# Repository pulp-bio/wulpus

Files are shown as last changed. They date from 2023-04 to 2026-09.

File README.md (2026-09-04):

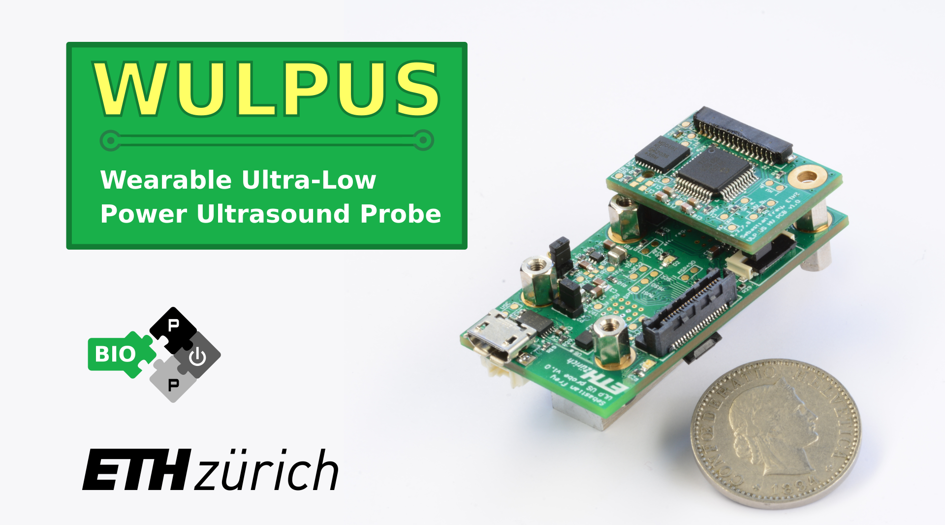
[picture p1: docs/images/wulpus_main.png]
WULPUS main


# WULPUS v1.2.4
## Wearable Ultra Low-Power Ultrasound

# Introduction

This repository contains the work in progress on the WULPUS ultrasound probe.

WULPUS is a truly wearable ultra-low-power open research ultrasound platform. 

The probe has the following features:
- **8 channels** (time-multiplexed)
- **8 Msps** Analog-to-Digital converter (12 bit resolution)
- **30.8 dB** Programable-Gain Amplifier + **10 dB** Operational Amplifier
- **Bluetooth Low Energy** (BLE) wireless link (320 kbps throughput)
- Up to **50 acquisitions per-second** (APS) (400 samples per acquisition, raw data streaming mode)
- **Compactness and light weight** (46 x 25 mm footprint, 9 g)
- **Ultra-Low Power** consumption of **22 mW** (raw data streaming mode, 50 APS)

# WULPUS system diagram

WULPUS probe comprises two printed circuit boards (PCBs):
- Acquisition PCB: featuring an ultrasound MCU (MSP430FR5043) and BLE MCU (nRF52832)
- High-Voltage PCB: featuring a High-voltage multiplexer (HV MUX), a transmit/receive switch, and a MOSFET driver.

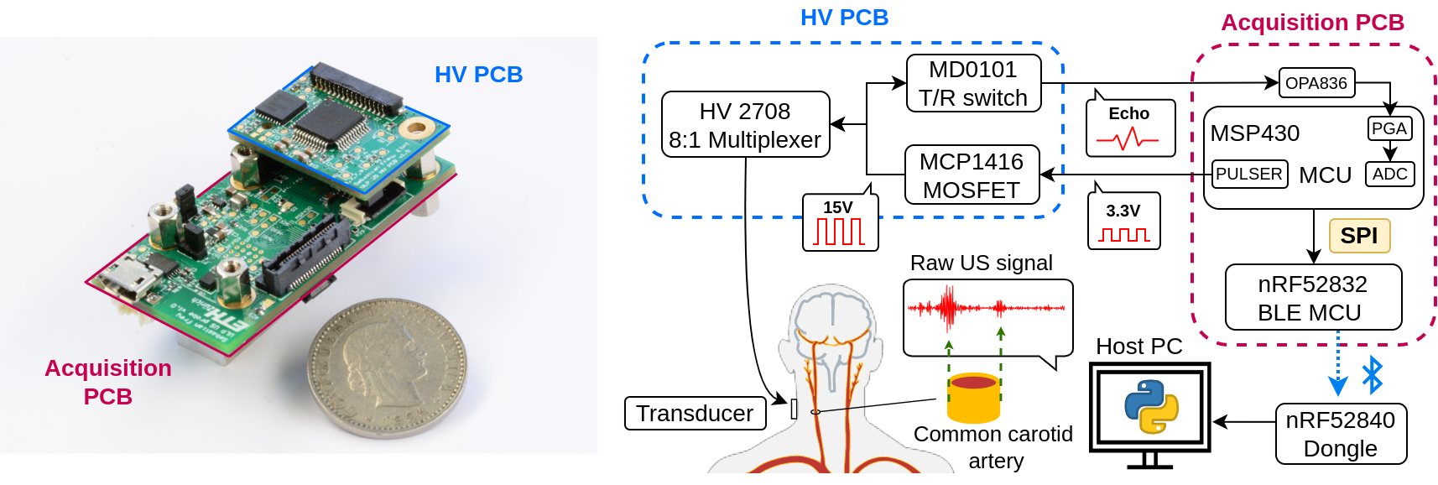
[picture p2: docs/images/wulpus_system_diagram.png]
WULPUS System Diagram

WULPUS System Diagram

# Structure of the repository

This repository has the following folders:

- `fw`, containing the firmware source code, namely:
    - source code for the nRF52832 MCU of the WULPUS probe, located at `fw/nrf52/ble_peripheral/US_probe_nRF52_firmware`
    - source code for the nRF52840 USB dongle, located at `fw/nrf52/peripheral/US_probe_dongle_firmware`
    - source code for the MSP430 ultrasound MCU, located at `fw/msp430`
- `sw`, containing the Python code for the WULPUS Graphical User Interface (web-based version).
 
- `hw`, containing the CAD source files for 
    - WULPUS Acquisition PCB (located at `hw/wulpus_acquisition_pcb`)
    - WULPUS High-Voltage PCB (located at `hw/wulpus_hv_pcb`)
    - WULPUS Programmer PCBs (located at `hw/wulpus_programmer_pcbs`)
    - WULPUS Silicone Rubber package (located at `hw/wulpus_silicone_package`)

- `docs`, containing the project documentation (e.g., images of the device, user manual, ...)

# Documentation 

The comprehensive [WULPUS User Manual](docs/wulpus_user_manual.pdf) can be found in the `docs/` folder. It covers everything about WULPUS, from assembly instructions to example measurements and troubleshooting, making the platform user-friendly for everyone, regardless of technical expertise.

# How to use?

Please find the detailed instructions in chapter 2 of the [WULPUS User Manual](docs/wulpus_user_manual.pdf).

In a nutshell, to build your own instance of WULPUS, the following steps should be completed:
1. *PCBs manufacturing and assembly*<br>
   You can find the design files (Altium source files, schematics, bills of materials) under the `hw` folder.
2. *Flashing MSP430 firmware*<br>
   You can find the instructions on setting up the toolchain, compiling the firmware and flashing the MSP430 MCU in the `fw/msp430` folder.
3. *Flashing nRF52 MCU and USB dongle firmware*<br>
   You can find the instructions on setting-up the toolchain, compiling the firmware, flashing the nRF52 MCU and USB dongle in the `fw/nrf52` folder.
4. *GUI installation on the host PC*<br>
   Choose one of the following interfaces depending on your application:
   - **BioGUI** *(Recommended for general use & HMI applications)*: Modular PySide6 GUI for acquiring and visualizing bio-signals from different sources. Follow the setup instructions in the [BioGUI repository](https://github.com/pulp-bio/biogui).
   - **Web-based GUI** *(Recommended for NDT applications & acquisition sequences)*: Features a React/Vite frontend and FastAPI backend. Follow the setup instructions in [`sw/`](sw/).
   - **Legacy Jupyter Notebook GUI** *(Deprecated / not recommended for new projects)*: Legacy interactive notebooks are located in [`sw/jupyter notebook (legacy)/`](<sw/jupyter notebook (legacy)/>).

# Usage

Please refer to chapter 3 of the [WULPUS User Manual](docs/wulpus_user_manual.pdf) for detailed information.

Starting a measurement with WULPUS can be accomplished in three simple steps:
- Power up the probe, either from the micro-USB connector or from the battery connector
- Connect the USB dongle to the host PC
- Launch your chosen interface (**[BioGUI repository](https://github.com/pulp-bio/biogui)** or the **Web-based GUI** in [`sw/`](sw/)).

# Citation
If you would like to reference the project, please cite the following paper:

```
@inproceedings{frey2022wulpus,
  title={WULPUS: a Wearable Ultra Low-Power Ultrasound probe for multi-day monitoring of carotid artery and muscle activity},
  author={Frey, Sebastian and Vostrikov, Sergei and Benini, Luca and Cossettini, Andrea},
  booktitle={2022 IEEE International Ultrasonics Symposium (IUS)},
  pages={1--4},
  year={2022},
  organization={IEEE}
}
```
# Works that use WULPUS

[1] Vostrikov, Sergei, et al. "Hand gesture recognition via wearable ultra-low power ultrasound and gradient-boosted tree classifiers." 2023 IEEE International Ultrasonics Symposium (IUS). IEEE, 2023.

[2] Vostrikov, Sergei, Luca Benini, and Andrea Cossettini. "Complete Cardiorespiratory Monitoring via Wearable Ultra Low Power Ultrasound." 2023 IEEE International Ultrasonics Symposium (IUS). IEEE, 2023.

[3] Frey, Sebastian, et al. "A wearable ultra-low-power semg-triggered ultrasound system for long-term muscle activity monitoring." 2023 IEEE International Ultrasonics Symposium (IUS). IEEE, 2023.

[4] Vostrikov S, Anderegg M, Benini L, Cossettini A. "Unsupervised Feature Extraction from Raw Data for Gesture Recognition with Wearable Ultra Low-Power Ultrasound." IEEE Transactions on Ultrasonics, Ferroelectrics, and Frequency Control. 2024 May 24.

[5] Spacone G, Vostrikov S, Kartsch V, Benatti S, Benini L, Cossettini A. "Tracking of Wrist and Hand Kinematics with Ultra Low Power Wearable A-mode Ultrasound." IEEE Transactions on Biomedical Circuits and Systems. 2024 Sep 23.

[6] Spacone, Giusy, et al. "Wearable and Ultra-Low-Power Fusion of EMG and A-Mode US for Hand-Wrist Kinematic Tracking." 2025 IEEE Biomedical Circuits and Systems Conference (BioCAS). IEEE, 2025.

[7] Spacone, Giusy, et al. "Towards Fully Wearable Muscle Fatigue Assessment with A-mode Ultrasound." 2025 IEEE International Ultrasonics Symposium (IUS). IEEE, 2025.

[8] Spacone, Giusy, et al. "Towards Whole Hand and Wrist Kinematic Tracking with a Wearable A-Mode Ultrasound Probe." IEEE Open Journal of Ultrasonics, Ferroelectrics, and Frequency Control. 2026.

# Authors

The WULPUS system was developed at the [Integrated Systems Laboratory (IIS)](https://iis.ee.ethz.ch/) at ETH Zurich by:
- [Sergei Vostrikov](https://scholar.google.com/citations?user=a0KNUooAAAAJ&hl=en) (Firmware, Software, Open-Sourcing, Documentation)
- [Sebastian Frey](https://scholar.google.com/citations?user=7jhiqz4AAAAJ&hl=en) (Firmware, PCB design, Documentation)
- [Luca Benini](https://scholar.google.com/citations?hl=en&user=8riq3sYAAAAJ) (Supervision, Conceptualization)
- [Andrea Cossettini](https://scholar.google.com/citations?user=d8O91jIAAAAJ&hl=en) (Supervision, Project administration)

Thanks to all the people who contributed to the WULPUS platform:
- [Cédric Hirschi](https://www.linkedin.com/in/c%C3%A9dric-cyril-hirschi-09624021b/) (GUI improvements, Documentation)
- [Josquin Tille](https://www.linkedin.com/in/josquin-tille-829a341a7/) (Silicone package design, Documentation)
- [William Bruderer](https://www.linkedin.com/in/william-bruderer-59ba9b26b/) (Documentation)
- [Louis Dod](https://github.com/13Bytes) (GUI Rework)

# License
The following files are released under Apache License 2.0 (`Apache-2.0`) (see `sw/LICENSE`):

- `sw/`

The following files are released under Solderpad v0.51 (`SHL-0.51`) (see `hw/LICENSE`):

- `hw/`

The following files are released under Creative Commons Attribution 4.0 International
License (`CC-BY-4.0`) (see `docs/images/LICENSE`):

- `docs/images/`

The `fw/msp430/` and `fw/nrf52/` directories contain third-party sources that come with their own
licenses. See the respective folders and source files for the licenses used.

## Limitation of Liability
In no event and under no legal theory, whether in tort (including negligence), contract, or otherwise, unless required by applicable law (such as deliberate and grossly negligent acts) or agreed to in writing, shall any Contributor be liable to You for damages, including any direct, indirect, special, incidental, or consequential damages of any character arising as a result of this License or out of the use or inability to use the Work (including but not limited to damages for loss of goodwill, work stoppage, computer failure or malfunction, or any and all other commercial damages or losses), even if such Contributor has been advised of the possibility of such damages.

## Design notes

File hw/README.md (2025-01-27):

# WULPUS HW design files
This directory contains the design files for the printed circuit boards (PCBs) of the WULPUS project and 3D models required to fabricate soft silicone rubber package for WULPUS.
The following directories corresponds to PCB projects:

-`hw/wulpus_acquisition_pcb`
-`hw/wulpus_hv_pcb`
-`hw/wulpus_programmer_pcbs`
-`hw/wulpus_silicone_package`

 Inside you can find the Altium CAD design files and generated schematics (.pdf), bill of materials (.xlsx) and Gerber files located in the `docs` subfolders.

 The following repository contains the 3D models required to fabricate soft silicone rubber package for WULPUS:
 -`hw/wulpus_silicone_package`

# License
The source design files are licensed under Solderpad v0.51 (`SHL-0.51`) license. Please, check the `hw/LICENSE` file for details.

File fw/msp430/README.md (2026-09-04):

# WULPUS source files for MSP430 Ultrasound MCU firmware project
This directory contains the source firmware files for 
- MSP430FR5043 Ultrasound MCU (`fw/msp430/wulpus_msp430_firmware`) mounted on the WULPUS acquisition PCB 

# How to get started?

1. Follow the file `fw/msp430/how_to_setup_msp_430_toolchain_and_flash.md` to install the toolchain and SDK
2. Follow the same file to flash the MSP430 MCU on the WULPUS acquisition PCB.

# License
The files in the `fw/msp430/wulpus_msp430_firmware` directory contain third-party sources that come with their own licenses (primarily BSD and Apache 2.0 License). See the respective folders and source files' headers for the licenses used.

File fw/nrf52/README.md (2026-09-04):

# WULPUS source files for nRF BLE MCU firmware projects
This directory contains the source files for 
- nRF52832 BLE MCU (`fw/nrf52/ble_peripheral`) mounted on the WULPUS acquisition PCB
- nRF52840 Dongle (`fw/nrf52/peripheral`) used to receive the ultrasound data on a host PC

# How to get started?

1. Follow the file `fw/nrf52/how_to_setup_nRF52_toolchain.md` to install the toolchain and SDK
2. Follow the file `fw/nrf52/how_to_flash_nrf52832.md` to flash the nRF MCU on the WULPUS acquisition PCB
3. Follow the file `fw/nrf52/how_to_flash_nrf52840_dongle.md` to flash the nRF52840 Dongle

# License
The files in the `fw/nrf52/ble_peripheral` and `fw/nrf52/peripheral` directories contain third-party sources that come with their own licenses. See the respective folders and source files' headers for the licenses used.

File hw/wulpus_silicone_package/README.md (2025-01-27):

# WULPUS Silicone Rubber Package Design Files
This directory contains the design files for the molds required to fabricate the soft silicone rubber package for WULPUS.

## Design Files for FDM 3D Printers
For the main package, use the following design files optimized for FDM 3D printing:
- `wulpus_inside_mold_fdm.stl`
- `wulpus_outside_mold_fdm.stl`

## Design Files for SLA 3D Printers
If you plan to order molds from an external supplier using SLA technology, please use these files:
- `wulpus_inside_mold_resin.stl`
- `wulpus_outside_mold_resin.stl`

## Compatibility Note
The above sets of 3D models are tailored to the specific tolerances required for FDM and SLA technologies. 

## Silicone Cap Mold
The following 3D model can be used with both FDM and SLA printers:
- `wulpus_silicone_cap_mold.stl`

## Fabrication Instructions
For detailed instructions on the fabrication process, refer to the [WULPUS User Manual](../../docs/wulpus_user_manual.pdf).

# License
The source design files are licensed under the Solderpad v0.51 (`SHL-0.51`) license. For more details, please refer to the `hw/LICENSE` file.

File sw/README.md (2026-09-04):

# WULPUS GUI source files
This directory contains the source files for WULPUS Graphical User Interface and an example Jupyter notebook ([wulpus_gui.ipynb](./jupyter%20notebook%20%28legacy%29/wulpus_gui.ipynb)).

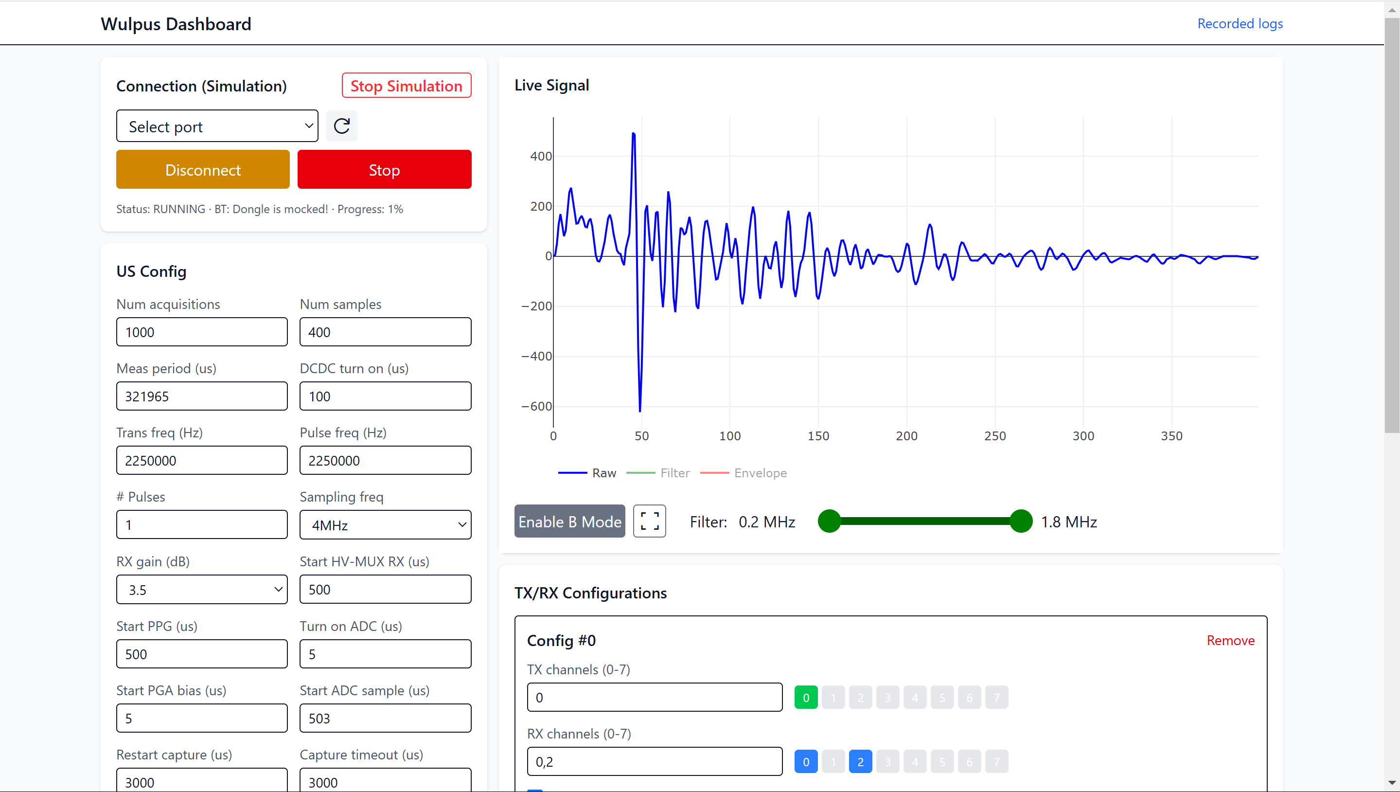
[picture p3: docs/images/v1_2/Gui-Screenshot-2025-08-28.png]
WULPUS GUI Screenshot


# How to get started?
## Prebuilt GUI (Windows)
The simplest way to run the WULPUS GUI on Windows is to use the prebuilt executable:

1. Download the latest `wulpus-all-in-one` artifact from the [WULPUS releases page](https://github.com/pulp-bio/wulpus/releases/latest).
2. Extract the downloaded zip file.
3. Start `main.exe`.
4. Open [http://127.0.0.1:8000/](http://127.0.0.1:8000/) in your browser.

Windows may show a security warning because the executable is not signed. If you downloaded it from the official release page, choose "More info" and then "Run anyway".

## Run from source
The Jupyter notebook requires only the Python dependencies, while the web-based GUI also requires the Node.js dependencies.

### Install dependencies
Install [uv](https://docs.astral.sh/uv/getting-started/installation/), then install the Python dependencies from `sw`:

```sh
uv sync
```

Install the Node.js dependencies from `sw/wulpus-frontend`:

```sh
npm i
```

### Initial build
Build the frontend and copy the results into the backend's production frontend directory:

```sh
python build.py
```

### User interface
How to launch the user interface from source:

- After completing the initial build, open a new terminal and navigate into `/sw`
- Start the backend with uv:
```
    uv run python -m wulpus.main
```
You should be able to open a browser of your choice and visit [http://127.0.0.1:8000/](http://127.0.0.1:8000/)

#### Using the log file
The log recorded by the user interface is a zip file called `wulpus-{date}-id-{connection}.zip`.
The date is the start of the recording, with the connection describes which wulpus was used (MAC address or COM port).
It contains the config from the job, as well as the data in a [parquet](https://parquet.apache.org/) file.

The parquet file contains the following rows:
- `tx`: list of channels used for sending
- `rx`: list of channels used for receiving
- `aq_number`: ID increased by the wulpus (can be used to detect lost frames)
- `log_version`: the current version of the log-format. Constant over the whole file. 
- `tx_rx_id`: the index of the tx-rx-config used
- `0`, `1`, `2`, ...`{num samples - 1}`: the actual data, readout from ADC
- `__index_level_0__`: unix timestamp in us

You can use the jupyter notebook [visualize_log.ipynb](visualize_log.ipynb) to load a single or a set of multiple measurements and evaluate them.
There is also [MATLAB_load_wulpus_log.m](MATLAB_load_wulpus_log.m) to help import the logs into MATLAB.

### Jupyter notebook (legacy)
How to Launch an example Jupyter notebook:
- In a terminal launch:
```
    uv run --extra notebook jupyter notebook
```
This opens a webpage: Navigate to `jupyter notebook (legacy)` and click on `wulpus_gui.ipynb`.
Then, follow the instructions in the Notebook.

# More details
The folder structure inside `/sw` is as follows:
- `wulpus-frontend` is a React project for the interface you see in your browser
- `wulpus` is a FastAPI server that controls communication with wulpus.
- `jupyter notebook (legacy)` is a standalone python-only solution which uses a jupyter notebook for controlling wulpus. 

During the build-step of `wulpus-frontend`, the build results are copied inside `wulpus\production-frontend`. This is how the frontend can be served from the `wulpus` FastAPI project.

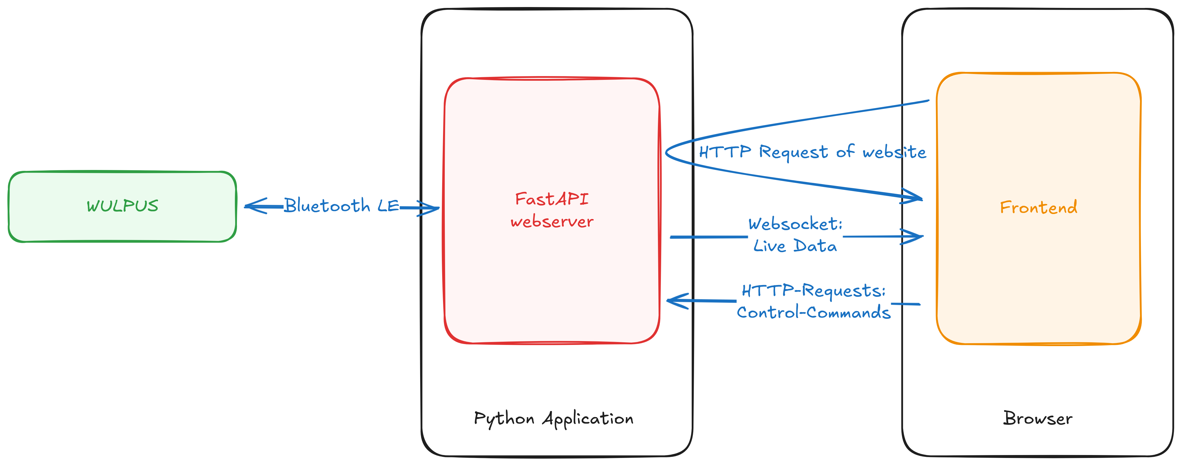
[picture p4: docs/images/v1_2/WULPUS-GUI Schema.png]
WULPUS GUI Schema


## Development
If you want to work on the frontend, it's easier to run the backend (`wulpus`) and the frontend (`wulpus-frontend`) separately.
This way you don't have to build after each step.

You can start the backend as usual (see above `uv run python -m wulpus.main`), but instead of visiting [http://127.0.0.1:8000/](http://127.0.0.1:8000/) in your browser, you start the development environment of the frontend:
- Open an additional terminal at `\sw\wulpus-frontend`
- run 
```
    npm run dev
```
- open the displayed link in your browser (probably [http://localhost:5173/](http://localhost:5173/))

This way, you access the frontend through its own dev server, which does hot reloading.
It still accesses the same backend, so everything still works exactly the same.

# License
The source files are released under Apache v2.0 (`Apache-2.0`) license unless noted otherwise, please refer to the `sw/LICENSE` file for details.

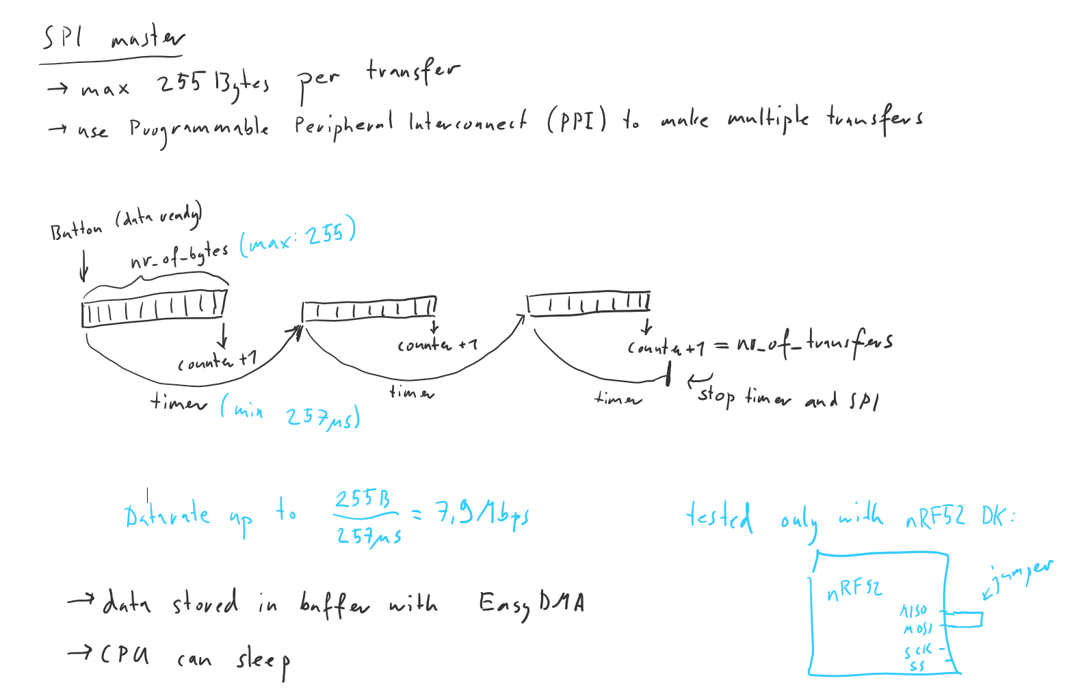
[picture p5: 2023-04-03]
fw/nrf52/ble_peripheral/US_probe_nRF52_firmware/Explanation_of_SPI_transaction.PNG

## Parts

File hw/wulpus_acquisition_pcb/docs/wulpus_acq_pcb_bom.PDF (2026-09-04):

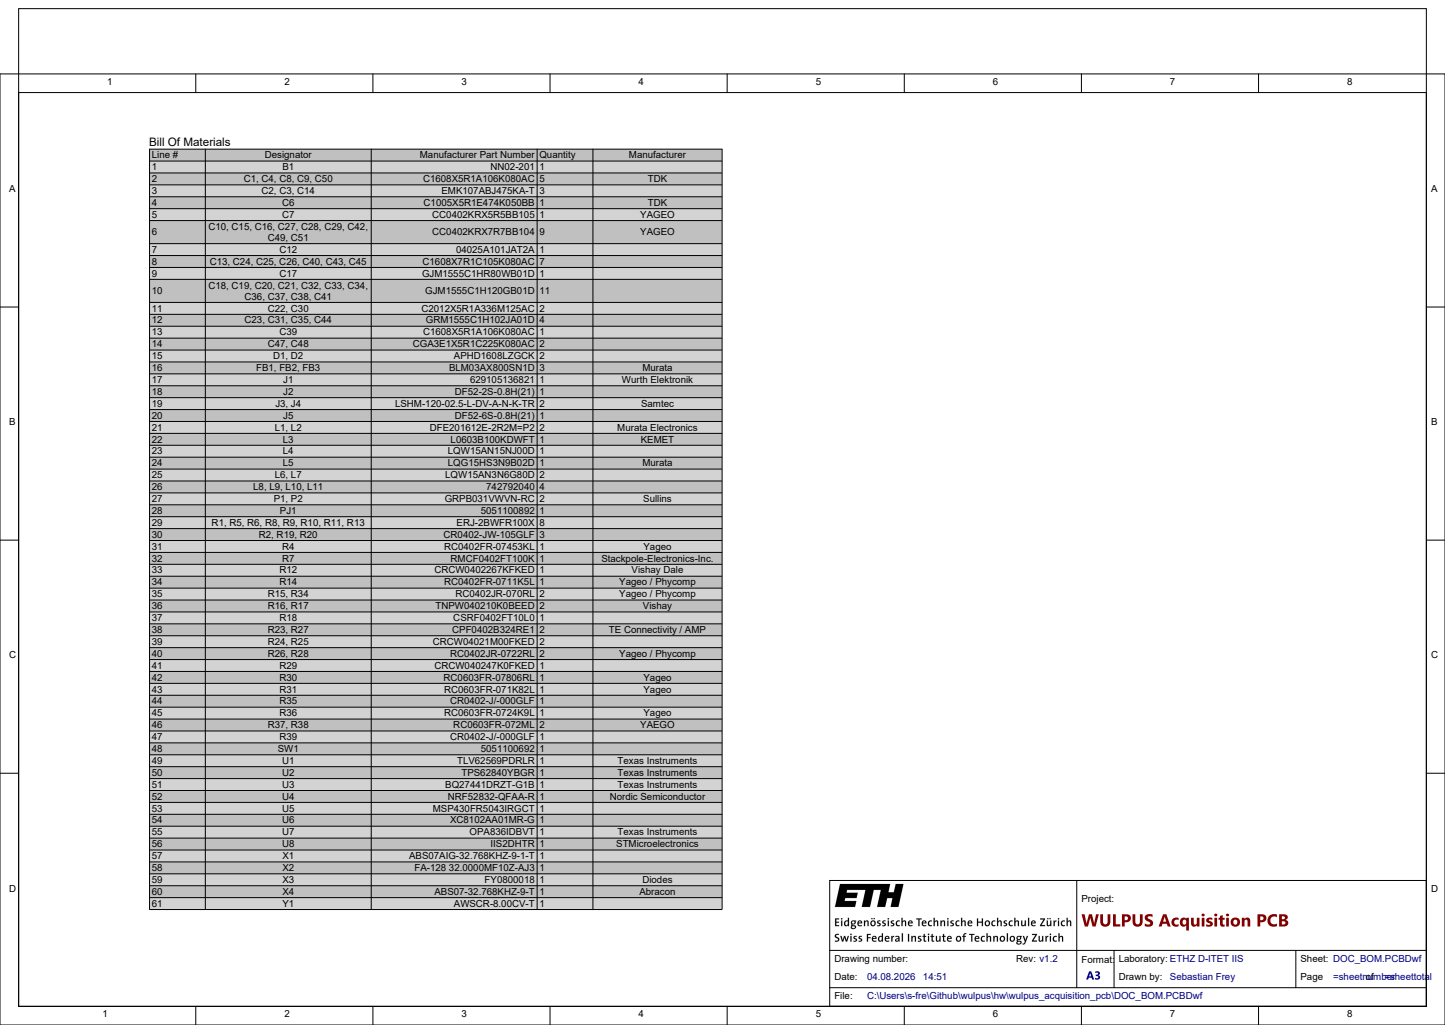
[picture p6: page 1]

Line # | Designator | Manufacturer Part Number | Quantity | Manufacturer
1 | B1 | NN02-201 | 1
2 | C1, C4, C8, C9, C50 | C1608X5R1A106K080AC | 5 | TDK
3 | C2, C3, C14 | EMK107ABJ475KA-T | 3
4 | C6 | C1005X5R1E474K050BB | 1 | TDK
5 | C7 | CC0402KRX5R5BB105 | 1 | YAGEO
6 | C10, C15, C16, C27, C28, C29, C42, C49, C51 | CC0402KRX7R7BB104 | 9 | YAGEO

7 | C12 | 04025A101JAT2A | 1
8 | C13, C24, C25, C26, C40, C43, C45 | C1608X7R1C105K080AC | 7
9 | C17 | GJM1555C1HR80WB01D | 1
10 | C18, C19, C20, C21, C32, C33, C34, C36, C37, C38, C41 | GJM1555C1H120GB01D | 11

11 | C22, C30 | C2012X5R1A336M125AC | 2
12 | C23, C31, C35, C44 | GRM1555C1H102JA01D | 4
13 | C39 | C1608X5R1A106K080AC | 1
14 | C47, C48 | CGA3E1X5R1C225K080AC | 2
15 | D1, D2 | APHD1608LZGCK | 2
16 | FB1, FB2, FB3 | BLM03AX800SN1D | 3 | Murata
17 | J1 | 629105136821 | 1 | Wurth Elektronik
18 | J2 | DF52-2S-0.8H(21) | 1
19 | J3, J4 | LSHM-120-02.5-L-DV-A-N-K-TR | 2 | Samtec
20 | J5 | DF52-6S-0.8H(21) | 1
21 | L1, L2 | DFE201612E-2R2M=P2 | 2 | Murata Electronics
22 | L3 | L0603B100KDWFT | 1 | KEMET
23 | L4 | LQW15AN15NJ00D | 1
24 | L5 | LQG15HS3N9B02D | 1 | Murata
25 | L6, L7 | LQW15AN3N6G80D | 2
26 | L8, L9, L10, L11 | 742792040 | 4
27 | P1, P2 | GRPB031VWVN-RC | 2 | Sullins
28 | PJ1 | 5051100892 | 1
29 | R1, R5, R6, R8, R9, R10, R11, R13 | ERJ-2BWFR100X | 8
30 | R2, R19, R20 | CR0402-JW-105GLF | 3

32 | R7 | RMCF0402FT100K | 1 | Stackpole-Electronics-Inc.
33 | R12 | CRCW0402267KFKED | 1 | Vishay Dale
34 | R14 | RC0402FR-0711K5L | 1 | Yageo / Phycomp
35 | R15, R34 | RC0402JR-070RL | 2 | Yageo / Phycomp
36 | R16, R17 | TNPW040210K0BEED | 2 | Vishay
37 | R18 | CSRF0402FT10L0 | 1
38 | R23, R27 | CPF0402B324RE1 | 2 | TE Connectivity / AMP
39 | R24, R25 | CRCW04021M00FKED | 2
40 | R26, R28 | RC0402JR-0722RL | 2 | Yageo / Phycomp
41 | R29 | CRCW040247K0FKED | 1
42 | R30 | RC0603FR-07806RL | 1 | Yageo
43 | R31 | RC0603FR-071K82L | 1 | Yageo
44 | R35 | CR0402-J/-000GLF | 1
45 | R36 | RC0603FR-0724K9L | 1 | Yageo
46 | R37, R38 | RC0603FR-072ML | 2 | YAEGO
47 | R39 | CR0402-J/-000GLF | 1
48 | SW1 | 5051100692 | 1
49 | U1 | TLV62569PDRLR | 1 | Texas Instruments
50 | U2 | TPS62840YBGR | 1 | Texas Instruments
51 | U3 | BQ27441DRZT-G1B | 1 | Texas Instruments
52 | U4 | NRF52832-QFAA-R | 1 | Nordic Semiconductor
53 | U5 | MSP430FR5043IRGCT | 1
54 | U6 | XC8102AA01MR-G | 1
55 | U7 | OPA836IDBVT | 1 | Texas Instruments
56 | U8 | IIS2DHTR | 1 | STMicroelectronics
57 | X1 | ABS07AIG-32.768KHZ-9-1-T | 1
58 | X2 | FA-128 32.0000MF10Z-AJ3 | 1
59 | X3 | FY0800018 | 1 | Diodes
60 | X4 | ABS07-32.768KHZ-9-T | 1 | Abracon
61 | Y1 | AWSCR-8.00CV-T | 1

Project:

Drawing number: Rev: v1.2 Date: 04.08.2026 14:51 | Format: | Laboratory: ETHZ D-ITET IIS Drawn by: Sebastian Frey | Sheet: DOC_BOM.PCBDwf Page =sheetnumber of =sheettotal

C:\Users\s-fre\Github\wulpus\hw\wulpus_acquisition_pcb\DOC_BOM.PCBDwf

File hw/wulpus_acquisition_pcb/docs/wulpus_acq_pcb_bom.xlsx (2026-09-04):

Designator | Comment | Quantity | Manufacturer
B1 | NN02-201 | 1
C1, C4, C8, C9, C39, C50 | C1608X5R1A106K080AC | 6 | TDK, [NoParam]
C2, C3, C14 | EMK107ABJ475KA-T | 3
C6 | C1005X5R1E474K050BB | 1 | TDK
C7 | CC0402KRX5R5BB105 | 1 | YAGEO
C10, C15, C16, C27, C28, C29, C42, C49, C51 | CC0402KRX7R7BB104 | 9 | YAGEO
C12 | 04025A101JAT2A | 1
C13, C24, C25, C26, C40, C43, C45 | C1608X7R1C105K080AC | 7
C17 | GJM1555C1HR80WB01D | 1
C18, C19, C20, C21, C32, C33, C34, C36, C37, C38, C41 | GJM1555C1H120GB01D | 11
C22, C30 | C2012X5R1A336M125AC | 2
C23, C31, C35, C44 | GRM1555C1H102JA01D | 4
C47, C48 | GRM188R61C225KE15D | 2
D1, D2 | APHD1608LZGCK | 2
FB1, FB2, FB3 | BLM03AX800SN1D | 3 | Murata
J1 | 629105136821 | 1 | Wurth Elektronik
J2 | DF52-2S-0.8H(21) | 1
J3, J4 | LSHM-120-02.5-L-DV-A-N-K-TR | 2 | Samtec
J5 | DF52-6S-0.8H(21) | 1
L1, L2 | DFE201612E-2R2M=P2 | 2 | Murata Electronics
L3 | L0603B100KDWFT | 1 | KEMET
L4 | LQW15AN15NJ00D | 1
L5 | LQG15HS3N9B02D | 1 | Murata
L6, L7 | LQW15AN3N6G80D | 2
L8, L9, L10, L11 | 742792040 | 4
P1, P2 | GRPB031VWVN-RC | 2 | Sullins
PJ1 | 5051100892 | 1
R1, R5, R6, R8, R9, R10, R11, R13 | ERJ-2BWFR100X | 8
R2, R19, R20 | CR0402-JW-105GLF | 3
R4 | RC0402FR-07453KL | 1 | Yageo
R7 | RMCF0402FT100K | 1 | Stackpole-Electronics-Inc.
R12 | CRCW0402267KFKED | 1 | Vishay Dale
R14 | RC0402FR-0711K5L | 1 | Yageo / Phycomp
R15, R34 | RC0402JR-070RL | 2 | Yageo / Phycomp
R16, R17 | TNPW040210K0BEED | 2 | Vishay
R18 | CSRF0402FT10L0 | 1
R23, R27 | CPF0402B324RE1 | 2 | TE Connectivity / AMP
R24, R25 | CRCW04021M00FKED | 2
R26, R28 | RC0402JR-0722RL | 2 | Yageo / Phycomp
R29 | CRCW040247K0FKED | 1
R30 | RC0603FR-07806RL | 1 | Yageo
R31 | RC0603FR-071K82L | 1 | Yageo
R35, R39 | CR0402-J/-000GLF | 2
R36 | RC0603FR-0724K9L | 1 | Yageo
R37, R38 | RC0603FR-072ML | 2 | YAEGO
SW1 | 5051100692 | 1
U1 | TLV62569PDRLR | 1 | Texas Instruments
U2 | TPS62840YBGR | 1 | Texas Instruments
U3 | BQ27441DRZT-G1B | 1 | Texas Instruments
U4 | NRF52832-QFAA-R | 1 | Nordic Semiconductor
U5 | MSP430FR5043IRGCT | 1
U6 | XC8102AA01MR-G | 1
U7 | OPA836IDBVT | 1 | Texas Instruments
U8 | IIS2DHTR | 1 | STMicroelectronics
X1 | ABS07AIG-32.768KHZ-9-1-T | 1
X2 | FA-128 32.0000MF10Z-AJ3 | 1
X3 | FY0800018 | 1 | Diodes
X4 | ABS07-32.768KHZ-9-T | 1 | Abracon
Y1 | AWSCR-8.00CV-T | 1

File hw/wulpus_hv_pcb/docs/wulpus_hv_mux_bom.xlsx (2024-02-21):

Designator | Manufacturer Part Number | Quantity | Manufacturer
C1 | 06036D475KAT2A | 1
C2 | C0402C479C5GACTU | 1 | Kemet
C3, C4 | GRM188R61H225KE11D | 2
C5 | C0603C104M5RACTU | 1 | KEMET
C6 | GMK316BJ105KLHT | 1
C7, C8 | GRM188R60J106ME47D | 2
C12, C14, C18, C21 | C1608X5R1H105K080AB | 4 | TDK
C13, C15, C19, C22 | CC0603KRX7R9BB104 | 4 | YAGEO
C17 | CL05B103KB5NNNC | 1
D1 | ZHCS400QTA | 1 | Diodes
FB1 | BLM18PG300SH1D | 1
J1 | LSHM-120-02.5-L-DV-A-N-K-TR | 1 | Samtec
J2 | DF52-16S-0.8H(21) | 1
L1 | B82422A1103K100 | 1 | EPCOS-(TDK)
L2 | NR3012T4R7M | 1
R1, R4, R6, R8 | CSR0402FK1R00 | 4
R2, R3, R19 | ERJ-2GEJ101X | 3 | Panasonic
R5 | RC0402FR-072ML | 1 | Yageo / Phycomp
R7 | ERJ-2RKF1783X | 1 | Panasonic
R10, R11, R12, R13, R14, R15, R16, R17, R18, R21 | RC0402JR-070RL | 10 | Yageo / Phycomp
U1 | LT1945IMS#PBF | 1 | Linear Technology
U2 | TPS61222DCKR | 1 | Texas Instruments
U3, U6 | MCP1416T-E/OT | 2
U4 | HV2707T-C/R8X | 1 | Microchip
U5 | MD0101K6-G | 1

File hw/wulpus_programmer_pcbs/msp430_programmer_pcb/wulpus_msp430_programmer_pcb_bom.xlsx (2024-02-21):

Designator | Manufacturer Part Number | Quantity | Manufacturer
CONN_JW1 | 5051100892 | 1 | Molex
J_OLMX1 | SAMTEC-TST-110-01-X-DJ | 1 | Samtec

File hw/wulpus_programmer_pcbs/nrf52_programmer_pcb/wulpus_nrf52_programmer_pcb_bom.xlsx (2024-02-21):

Designator | Manufacturer Part Number | Quantity | Manufacturer
CONN_SWDN1 | 5051100692 | 1 | Molex
S_NRDC1 | SAMTEC-TST-110-01-X-DJ | 1 | Samtec

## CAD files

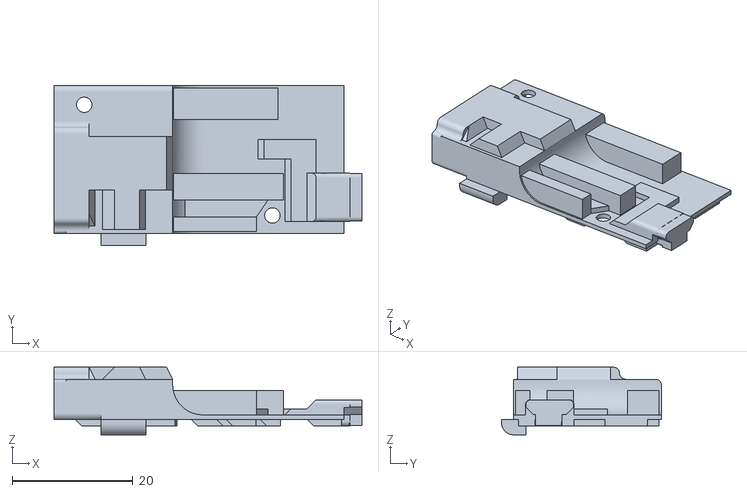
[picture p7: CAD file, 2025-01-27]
hw/wulpus_silicone_package/wulpus_inside_mold_resin.stl
51.0 x 26.5 x 11.2

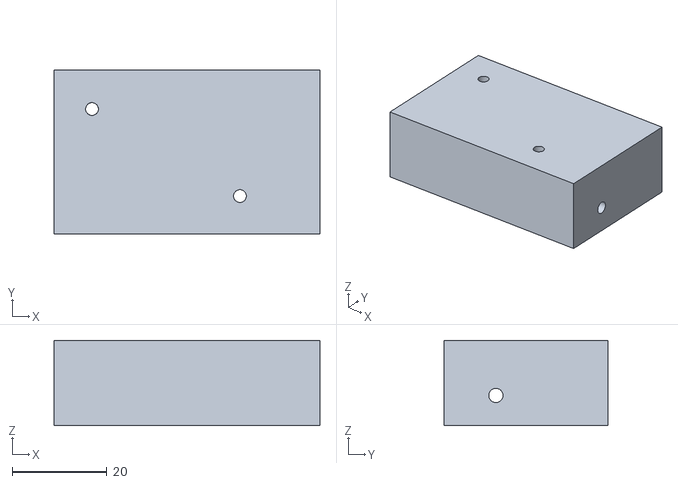
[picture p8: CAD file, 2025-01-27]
hw/wulpus_silicone_package/wulpus_outside_mold_fdm.stl
56.0 x 34.5 x 18.0

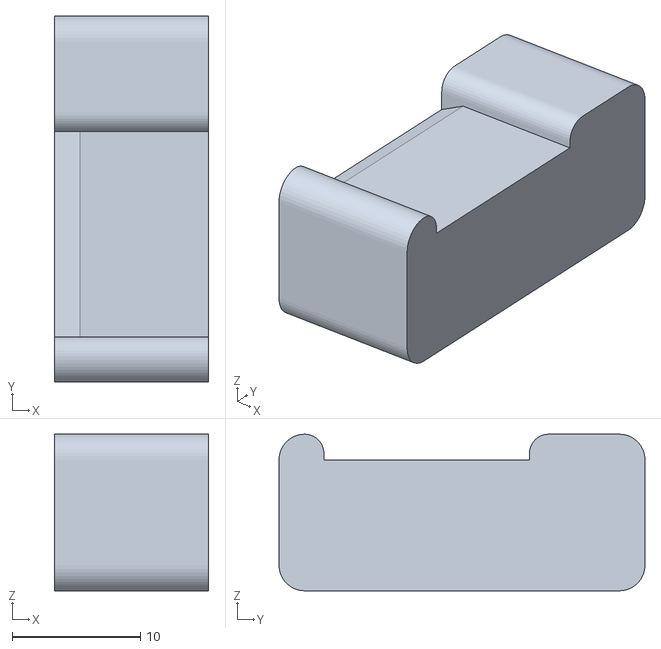
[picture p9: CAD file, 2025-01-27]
hw/wulpus_silicone_package/wulpus_silicone_cap_mold.stl
12.0 x 28.5 x 12.2

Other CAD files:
hw/wulpus_silicone_package/wulpus_outside_mold_resin.stl
hw/wulpus_silicone_package/wulpus_inside_mold_fdm.stl

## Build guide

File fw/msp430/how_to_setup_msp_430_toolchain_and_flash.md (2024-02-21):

# Setup of the TI MSP430 toolchain

### TI Code Composer Studio (CCS) (V11.0.0.00012):
`https://www.ti.com/tool/CCSTUDIO#downloads`
- Download the single file installer, extract it and run the ccs_setup_11.0.0.00012 file
- Choose custom installation
- In "Select Components", select MSP430 ultra-low power MCUs and finish the installation

# Flash the firmware to the MSP430

### To flash the MSP430 firmware:
Open the project in Code Composer Studio (CCS)
- Open CCS, set the workspace to default value
- Select File > Open Projects from File System...
- Select Directory, set it to `/fw/msp430/wulpus_msp430_firmware` and then click Finish
- Select Project > Build Configurations > Set Active > Debug
- Build the project
- Connect the MSP FET programmer to the US probe using the 8-pin Molex connector according to the diagram in the User Guide.
- Power the US probe with a battery or USB (Set the jumper P2 accordingly)
- Flash the code: Click on the Flash icon (if necessary select a binary file called `wulpus_msp430_firmware.out`)

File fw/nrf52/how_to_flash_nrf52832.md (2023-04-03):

# Flash the Nordic nRF52832 with Segger Embedded Studio (SES)

First, complete the toolchain setup, as described in **how_to_setup_nRF52_toolchain.md**

### To flash the US firmware to the nRF52832:

Open the project in SES:  
- Select File > Open Solution...
- Select the SES project:  
`nRF5_SDK_17.1.0/examples/ble_peripheral/US_probe_nRF52_firmware/pca10040/s132/ses/US_probe_nRF52_firmware.emProject`
- Connect the US probe with the j-link debugger and the 6-pin Molex connector
- Flash the code: Select Build > Build and Run
- The Softdevice (for BLE) is flashed automatically together with the rest of the code
- The nRF52832 needs a power cycle to start the execution of the code

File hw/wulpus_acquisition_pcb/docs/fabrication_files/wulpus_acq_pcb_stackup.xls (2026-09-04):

Board Stack Report
Stack Up |  | Layer Stack
Layer | Board Layer Stack | Name | Material | Thickness | Constant
1 |  | Top Paste
2 |  | Top Overlay
3 |  | Top Solder | Solder Resist | 0.010mm | 3.5
4 |  | Top Layer | Copper | 0.035mm
5 |  | Dielectric 1 | PP | 0.210mm | 4.36
6 |  | Signal Layer 1 | Copper | 0.015mm
7 |  | Dielectric 3 | Core | 0.500mm | 4.6
8 |  | Signal Layer 2 | Copper | 0.015mm
9 |  | Dielectric 2 | PP | 0.210mm | 4.36
10 |  | Bottom Layer | Copper | 0.035mm
11 |  | Bottom Solder | Solder Resist | 0.010mm | 3.5
12 |  | Bottom Overlay
13 |  | Bottom Paste
 | Height : 1.042mm

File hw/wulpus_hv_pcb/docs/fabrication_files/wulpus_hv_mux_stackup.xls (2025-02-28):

Board Stack Report
Stack Up |  | Layer Stack
Layer | Board Layer Stack | Name | Material | Thickness | Constant
1 |  | Top Paste
2 |  | Top Overlay
3 |  | Top Solder | Solder Resist | 0.010mm | 3.5
4 |  | Top Layer | Copper | 0.035mm
5 |  | Dielectric 1 | PP | 0.179mm | 4.74
6 |  | Signal Layer 1 | Copper | 0.036mm
7 |  | Dielectric 3 | Core | 0.430mm | 4.6
8 |  | Signal Layer 2 | Copper | 0.036mm
9 |  | Dielectric 2 | PP | 0.179mm | 4.74
10 |  | Bottom Layer | Copper | 0.035mm
11 |  | Bottom Solder | Solder Resist | 0.010mm | 3.5
12 |  | Bottom Overlay
13 |  | Bottom Paste
 | Height : 0.949mm

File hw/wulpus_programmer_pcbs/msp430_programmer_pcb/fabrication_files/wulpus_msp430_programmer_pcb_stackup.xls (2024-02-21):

Board Stack Report
Stack Up |  | Layer Stack
Layer | Board Layer Stack | Name | Material | Thickness | Constant
1 |  | Top Paste
2 |  | Top Overlay
3 |  | Top Solder | Solder Resist | 0.010mm | 3.5
4 |  | Top Layer | Copper | 0.036mm
5 |  | Dielectric 1 | FR-4 | 0.320mm | 4.8
6 |  | Bottom Layer | Copper | 0.036mm
7 |  | Bottom Solder | Solder Resist | 0.010mm | 3.5
8 |  | Bottom Overlay
9 |  | Bottom Paste
 | Height : 0.411mm

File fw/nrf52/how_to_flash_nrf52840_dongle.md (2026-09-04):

# Flash the Nordic nRF52840 dongle with Segger Embedded Studio (SES)

First, complete the toolchain setup, as described in **how_to_setup_nRF52_toolchain.md**

### To flash the US firmware to the nRF52840 dongle:

### First, the hex file of the C project has to be generated:  
Open the project in SES:  
- Select File > Open Solution...
- Select the SES project:  
`nRF5_SDK_17.1.0/examples/peripheral/US_probe_dongle_firmware/pca10059/s140/ses/US_probe_dongle_firmware.emProject`
- Generate the hex file: Select Build > Build US_probe_dongle_firmware
- The resulting `US_probe_dongle_firmware.hex` is located in the folder:  
`fw/nrf52/nRF5_SDK_17.1.0/examples/peripheral/US_probe_dongle_firmware/pca10059/s140/ses/Output/Debug/Exe/`

### Second, the Softdevice S140 7.2.0 is needed:  
Download a fresh copy:  
'https://www.nordicsemi.com/Products/Development-software/S140/Download?lang=en#infotabs'
- Download and unpack the Softdevice S140 in `nRF5_SDK_17.1.0/examples/peripheral/US_probe_dongle_firmware/s140_nrf52_7.2.0_softdevice.hex`

### Third, program the application and softdevice hex files:  
- Open nRF Connect for Desktop and launch the Programmer app.
- Plug the dongle into a USB port.
- Press the reset button to put the dongle in DFU mode. Note that the reset button is the sideways button right next to the more visible SW1 button on the dongle.
- Select the dongle in the dropdown in the upper left corner in the Programmer app.
- Click "Add HEX file" to select the application hex file to program onto the dongle.
- Click "Add HEX file" to select the Softdevice hex file downloaded above.
- Click "Write" to write the firmware to the dongle.

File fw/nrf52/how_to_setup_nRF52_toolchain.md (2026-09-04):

# Setup of the Nordic nRF52 toolchain for Segger Embedded Studio

For a more detailed Getting Started Guide with other IDE options:  
`https://infocenter.nordicsemi.com/index.jsp?topic=%2Fug_gsg_ses%2FUG%2Fgsg%2Fintro.html&cp=1_1_0`  
Go to: - Getting started with nRF5 SDK and SES (nRF51 & nRF52 Series)
			- Setting up your toolchain

### Segger Embedded Studio for ARM (V5.62):  
`https://www.segger.com/downloads/embedded-studio`
- Download and install

### Obtain a free license for SES:  
`https://license.segger.com/Nordic.cgi`
- Fill in the requested information, the licese is sent to your mail
- Open SES
- Click Tools > License Manager...
- Select Activate SEGGER Embedded Studio
- Paste in your license and click on Install License
Note: After clicking "Install License", it may take a few hours until the license is activated.

### Segger J-Link Software and Documentation Pack (V7.56a):  
`https://www.segger.com/downloads/jlink`
- Download and Install

### Nordic nRF Command Line Tools (V10.14.0):  
`https://www.nordicsemi.com/Products/Development-tools/nrf-command-line-tools/download`
- Download and install
- Check for path: nrfjprog --version

### Nordic nRF Connect for Desktop (V3.7.1):  
'https://www.nordicsemi.com/Products/Development-tools/nRF-Connect-for-desktop/Download#infotabs'
- Download and install it
- Open it and install the programmer app (V1.4.11)
- Needed to flash the nRF52 Dongle

### SoftDevice S140 (V7.2.0):  
`https://www.nordicsemi.com/Products/Development-software/S140/Download?lang=en#infotabs`
- Only needed for the nRF52840 Dongle
- For the nRF52832, this is automatically flashed by the IDE together with the compiled code

### Nordic nRF5 SDK (Software Development Kit) (V17.1.0):  
`https://www.nordicsemi.com/Products/Development-software/nRF5-SDK/Download#infotabs`
- Download and unpack
- Place the folder close to the root level of your file system (e.g. C:/Nordic/SDK)  
Note: Compilers tend to run into problems with long path names. Therefore, place the folder as close to the root level of your file system as possible (for example, at C:/Nordic/SDK). Also, avoid using spaces in the file path and folder name.
- Copy the folders `ble_peripheral` and `peripheral` to the `examples` folder of the SDK (e.g. copy to C:/Nordic/SDK/examples)
- Inside the copied folders (`ble_peripheral` and `peripheral`), you can find `.emProject` project files for WULPUS and USB-dongle firmware respectively. You can open these projects in Segger Embedded Studio.

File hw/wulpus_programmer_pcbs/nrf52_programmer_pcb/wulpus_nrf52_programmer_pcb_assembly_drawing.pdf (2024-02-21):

A

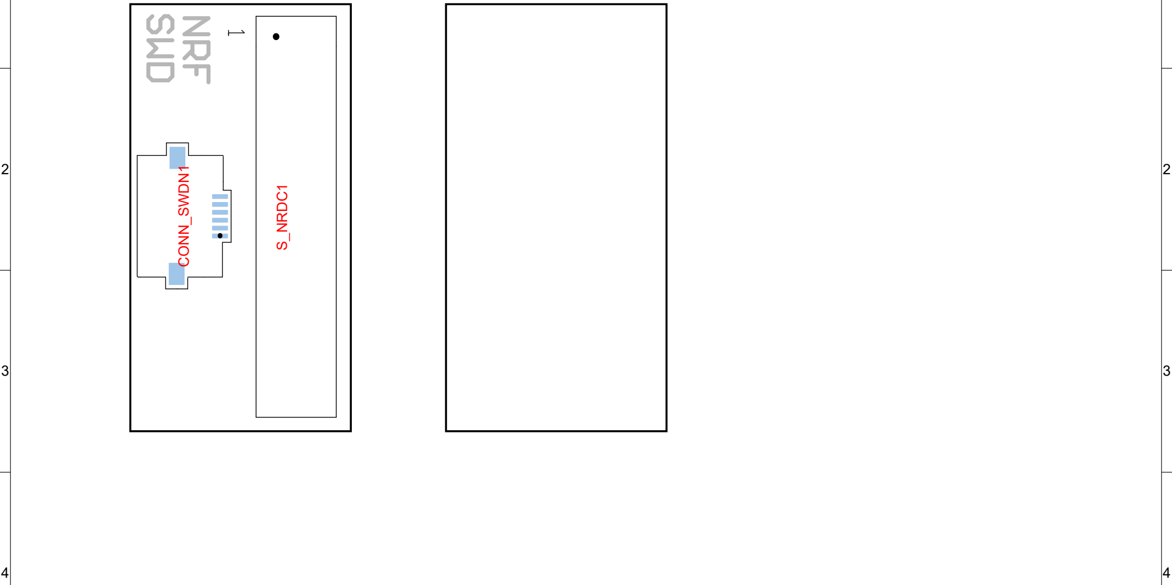
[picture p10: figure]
4 S_NRDC¹ CONN_SWDN¹

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
1 | 1
View from Top side (Scale 4:1) | View from Bottom side (Scale 4:1)

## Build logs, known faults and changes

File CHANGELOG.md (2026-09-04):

# Changelog

All main changes to this project will be documented in this file.
For the detailed description, please explore nested folders and corresponding CHANGELOG.md files (e.g. for PCB projects or firmware). 

The format is based on [Keep a Changelog](https://keepachangelog.com/en/1.0.0/),
and this project adheres to [Semantic Versioning](https://semver.org/spec/v2.0.0.html).

## [1.2.4] - 2026-08-31

### Added

### Fixed

- Acquisition PCB layout changes to improve RF performance
- Firmware improvements on nRF52 to improve reliability

### Changed

- Added new antenna (NN02-201) and corresponding matching network on Acquisition PCB

## [1.2.3] - 2026-04-02

### Added

- Added optional accelerometer streaming on the nRF52, enabled only when requested by the user configuration.

### Fixed

### Changed

## [1.2.2] - 2025-03-23

### Added

### Fixed

### Changed

- Updated Acquisition PCB layout to simplify the production requirements.

## [1.2.1] - 2025-02-12

### Added

### Fixed

### Changed

- Updated Acquisition PCB and HV PCB stackups. 
- Adjusted RF trace width according to the stackup to keep 50ohm impedance
- Updated the gerber files and stackup information for both Acquisition PCB and HV PCB.

### Removed

## [1.2.0] - 2025-01-27

### Added

- Fabrication instructions for the WULPUS silicone package (refer to WULPUS User Manual Rev. 2).  
- Source design files for the WULPUS silicone package (`/hw/wulpus_silicone_package`).  
- Updated repository description and an expanded list of contributors in `README.md`.  
- Added new publications utilizing the WULPUS probe to `README.md`.

### Fixed

- Resolved multiple inaccuracies in WULPUS User Manual Rev. 1 (#13, #15, #18, #22).  
- Fixed issue #17: Power supply spikes exceeding resistor power ratings. Added enable pin control for U1.  
- Addressed issue #21: Improved antenna layout for better performance.  
- Updated acquisition PCB layout and production files accordingly.

### Changed

- Replaced chip antenna on the Acquisition PCB and updated the matching circuit.

### Removed
- Removed mounting hole on the Acquisition PCB to allow for RF routing and antenna matching network adjustments.  

## [1.1.0] - 2024-02-21

### Added

- WULPUS User Manual Rev 1 (`docs/wulpus_user_manual.pdf`)
- MSP430 firmware (located at `fw/msp430`)
- WULPUS programmer PCBs' design files (located at `hw/wulpus_programmer_pcbs`).
- Generated production files (Assembly drawings, BOM, Gerber files, Drill files, Pick&Place files) for all the PCBs.
- Added the dedicated GUIs to configure the excitation/receive and measurement settings.
- Added example configurations and data.

### Fixed

- BLE Package loss by implementing buffering on the nRF52 MCU.
- Multiple GUI bugs.

### Changed

- Updated the design of the acquisition and high-voltage PCBs
- Improved the schematics of the PCB projects to simplify the outsourced assembly.
- Improved the main WULPUS GUI and an example script.

### Removed

- Removed `./sw/docs` folder with the old GUI guide. The information about the GUI is now available in the WULPUS user manual.

## [1.1.1] - 2024-12-18

### Added

- 

### Fixed

- Addressed issue #17 (Power supply spikes exceeding the resistors power rating. Enable pin control of the U1)

### Changed

- 

### Removed

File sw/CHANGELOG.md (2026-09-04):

# Changelog

All notable changes to this project will be documented in this file.

The format is based on [Keep a Changelog](https://keepachangelog.com/en/1.0.0/),
and this project adheres to [Semantic Versioning](https://semver.org/spec/v2.0.0.html).

## [1.2.0] - 2025-08-28

### Added

- A new web-based UI application (`wulpus-frontend/`, Vite + React) with panels for connection, TX/RX config, ultrasound config, logs, and live graphing.
  It has feature parity with the Jupyter notebook GUI.
- A new FastAPI backend service (`wulpus/`) exposing HTTP APIs and a WebSocket stream for live measurements; includes config and log endpoints.
- Recording functionality and compressed logging that includes the recording start timestamp.
- Mocked dongle, simulation, and replay modes to ease development and demonstrations.
- User-defined graph filter, fullscreen mode for the graph
- Configuration persistence across reloads via localStorage.

### Changed

- Moved the existing GUI from `/sw/wulpus` into `/sw/jupyter notebook (legacy)/wulpus_jptnbk`.
- Frontend is now served by the FastAPI backend.
- Refactored US acquisition setup; added capability to live-patch configuration during runtime.
- Reworked and typed the `latest_frame` data structure, enabling reliable B-mode visualization.

## [1.1.0] - 2024-02-21

### Added

- An opportunity to turn on algorithm for optimizing HV MUX switching. As a result, the switching artifacts are minimized.
- Updated RX/TX API and Python GUI accordingly (optional tick box to activate optimal switching).
- A STOP button to stop acquisition earlier.
- A GUI to configure/save/load TX and RX configurations of the HV multiplexer.
- A GUI to configure ultrasound subsystem parameters, and save them to or load them from a file.
- Comments/docstrings in the source files
- Added B-mode visualization option.
- The code in example jupyter notebook to load the data.

### Fixed

- Bug with empty COM port list (the GUI failed when there were no COM ports in the system).
- Now the user can rerun the main GUI cell without closing the COM port first.

### Changed

- WULPUS stops acquisitions after GUI acquired required number of samples.
- User can now directly change the sampling frequency and not the oversampling ratio.
- Band-pass filter's max/min boundaries are dynamically adapted depending on the sampling frequency.
- All the time-related parameters are now configured in us (not ticks).
- PGA gain can now be selected from a drop-down list.
- Moved visualization to a separate thread.

### Removed
- Removed `./docs` folder with the old GUI guide. The information about the GUI is now available in the WULPUS user manual.

-

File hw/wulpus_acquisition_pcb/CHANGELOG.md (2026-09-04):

# Changelog

All notable changes to this project will be documented in this file.

The format is based on [Keep a Changelog](https://keepachangelog.com/en/1.0.0/),
and this project adheres to [Semantic Versioning](https://semver.org/spec/v2.0.0.html).

## [1.2.4] - 2026-08-31

- Layout changes to improve RF performance (more antenna clearance, improved RF routing)

### Changed

- Added new antenna (NN02-201) and corresponding matching network

## [1.2.2] - 2025-03-23

### Added

### Fixed

### Changed

- Updated footprint of U4, U5 and U8 to release production complexity (increased vias hole diameter to 0.3 mm, left 0.22 mm spacing between the pads of U8 for the minimal solder mask sliver).

### Removed

## [1.2.1] - 2025-02-12

### Added

### Fixed

### Changed

- Updated stackup to a default PCBWay stackup (4 layers, 1mm thickness, 1oz inner copper, 1oz outer copper, 50% inner layer residual copper ratio) 
- Adjusted RF trace width according to the stackup to keep 50ohm impedance
- Updated the gerber files and stackup information

### Removed

## [1.2.0] - 2025-01-27

### Added

### Fixed

- Placed a weak pull-down resistor (R2) to fix the disabled state of TLV62569 (U1) by default
- Replaced R1, R5, R6, R8, R9, R10, R11, R13 with 0.1Ohm, 250mW resistors
- Addressed issue #21 (Missing ground plane for microstrip)

### Changed

- Replaced chip antenna to ignion NN03-320
- Changed matching curcuit accordingly

### Removed

- Mounting hole M3 (to make space for RF routing and matching network)

## [1.1.0] - 2024-02-21

### Added

- Board-to-wire connector J5, giving access to VCC, GND and two GPIO's of each MCU
- One button for each MCU (not mounted by default)
- Generated production files (Assembly drawing, BOM, Gerber files, Drill files, Pick&Place files)

### Fixed

- Marked various components as "Do not mount" (R33, R21, R32, R2, R3, C5, C46)

### Changed

- Replaced battery connector (new DF52-2S-0.8H(21))
- Replaced R35 with 0 Ohm jumper

### Removed

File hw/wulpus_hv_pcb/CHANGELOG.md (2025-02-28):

# Changelog

All notable changes to this project will be documented in this file.

The format is based on [Keep a Changelog](https://keepachangelog.com/en/1.0.0/),
and this project adheres to [Semantic Versioning](https://semver.org/spec/v2.0.0.html).

## [Unreleased]

## [1.1.1] - 2025-02-12

### Added

### Fixed

### Changed

- Updated Altium stackup to a default PCBWay stackup (4 layers, 1mm thickness, 1oz inner copper, 1oz outer copper, 50% inner layer residual copper ratio) 
- Regenerated fabrication files and stackup information

### Removed

## [1.1.0] - 2024-02-21

### Added

- Generated production files (Assembly drawing, BOM, Gerber files, Drill files, Pick&Place files)

### Fixed

- Marked various components as "Do not mount" (C9, C10, C11, C20, R9, C16)

### Changed

- Replaced high voltage multiplexer HV2708 to HV2707
- Replaced MOSFET MCP1402 to MCP1416
- Replaced R13, R14, R19 with 0 Ohm jumper
- Replaced R15 with 10 nF CAP
- Replaced C17 with 100 Ohm resistor

### Removed

 -

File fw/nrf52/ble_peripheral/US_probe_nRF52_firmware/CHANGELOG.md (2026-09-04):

# Changelog

All notable changes to this project will be documented in this file.

The format is based on [Keep a Changelog](https://keepachangelog.com/en/1.0.0/),
and this project adheres to [Semantic Versioning](https://semver.org/spec/v2.0.0.html).

## [1.2.4] - 2026-08-31

### Fixed

- Streaming could stop permanently, recoverable only by power cycling the probe. The interrupt that ends a frame's SPI burst had a small chance of being delayed by the SoftDevice; when delayed it allowed a fifth transfer, desynchronising the MSP430's fixed-size slave DMA. `DATA_READY` then stayed high, no further GPIOTE edge was produced, and both MCUs deadlocked with BLE still connected.
- I2C readout reliability improvements

### Changed

- `fw/nrf52/ble_peripheral/US_probe_nRF52_firmware/us_spi.c`: Stop the SPI burst over PPI from the transfer counter's CC0 event rather than from its interrupt handler, removing the dependency on interrupt latency. Uses the previously declared but unwired `counter1_cc0_evt_addr`.
- `fw/nrf52/ble_peripheral/US_probe_nRF52_firmware/main.c`: Clear both timers in `in_pin_handler()` so every frame starts from a known transfer count.
- `fw/nrf52/ble_peripheral/US_probe_nRF52_firmware/pca10040/s132/config/sdk_config.h`: Raised GPIOTE and TIMER interrupt priority from 6 to 2, off the SoftDevice dispatcher's level.
- `fw/nrf52/ble_peripheral/US_probe_nRF52_firmware/iis2dh.c`: Replaced six single-register accelerometer reads with one auto-incrementing burst read of `OUT_X_L..OUT_Z_H` and raised TWI from 100 kHz to 400 kHz, cutting main-loop blocking from roughly 2.4 ms to 0.2 ms per frame. Wire format unchanged.
- `fw/nrf52/ble_peripheral/US_probe_nRF52_firmware/iis2dh.h`: Added `IIS2DH_AUTO_INCREMENT` and the `CTRL_REG4` bit definitions.

## [1.2.3] - 2026-04-02

### Added

- Optional accelerometer streaming on the nRF52, enabled only when requested by the user configuration.
- `fw/nrf52/ble_peripheral/US_probe_nRF52_firmware/iis2dh.c`: Added IIS2DH accelerometer driver, runtime enable/disable handling, and ACC/non-ACC frame finalization.
- `fw/nrf52/ble_peripheral/US_probe_nRF52_firmware/iis2dh.h`: Added IIS2DH register definitions, types, and public driver API.

### Changed

- `fw/nrf52/ble_peripheral/US_probe_nRF52_firmware/main.c`: Added runtime accelerometer state handling and deferred mode application from the main loop.
- `fw/nrf52/ble_peripheral/US_probe_nRF52_firmware/us_ble.c`: Added config-packet parsing for user-requested accelerometer streaming and deferred update signaling.
- `fw/nrf52/ble_peripheral/US_probe_nRF52_firmware/us_spi.c`: Moved frame completion responsibility to the ACC/non-ACC post-processing path.
- `fw/nrf52/ble_peripheral/US_probe_nRF52_firmware/pca10040/s132/ses/US_probe_nRF52_firmware.emProject`: Added IIS2DH source files and TWI driver sources to the SES project.

## [1.1.0] - 2024-02-21

### Added

- 

### Fixed

- BLE Package loss by implementing buffering on the nRF52. As a consequence, an increased power consumption (+2-5 mW and more) can be observed in noisy RF environment.

### Changed

- Moved the main macro definitions to `us_defines.h`

### Removed

- Cleaned the old (not used) code

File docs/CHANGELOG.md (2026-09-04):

# Changelog

All notable changes to this project will be documented in this file.

The format is based on [Keep a Changelog](https://keepachangelog.com/en/1.0.0/),
and this project adheres to [Semantic Versioning](https://semver.org/spec/v2.0.0.html).

## [Unreleased]

## [1.3.0] - 2025-08-28

### Added
- New GUI with replay-functionality and extended logging, which is running in the browser
- This required a new API, which structures the way of communicating with the wulpus-server

(More details can be found in the [sw-changelog](../sw/CHANGELOG.md))

## [1.2.0] - 2025-01-27

### Added
- Fabrication instructions for the WULPUS silicone package (refer to WULPUS User Manual Rev. 2).

### Fixed
- Resolved multiple inaccuracies in WULPUS User Manual (#13, #15, #18, #22).  

## [1.1.0] - 2024-02-21

### Added

- WULPUS user manual Rev 1.
- Added the new photos of the WULPUS PCBs v1.1 folder into the dedicated subfolder (`./images/v1_1`).

### Fixed

### Changed

- Moved `./images` folder into the dedicated subfolder (`./images/v1_0`)

### Removed

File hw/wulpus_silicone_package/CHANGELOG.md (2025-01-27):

# Changelog

All notable changes to this project will be documented in this file.

The format is based on [Keep a Changelog](https://keepachangelog.com/en/1.0.0/),
and this project adheres to [Semantic Versioning](https://semver.org/spec/v2.0.0.html).

## [1.2.0] - 2025-01-27

### Added
- Design files for WULPUS silicone package
- Manufacturing instruction for silicone package in the WULPUS User Manual
### Fixed
### Changed
### Removed

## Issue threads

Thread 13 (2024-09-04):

questions for using the gui for measuring A-mode and B-mode data

TimChang1024, 2024-09-04:
Solved:
•	3.2 Software Requirements
Unsolved:
•	2.4.2 Flashing the Device
Locate the .emProject file in the US_probe_nRF52_firmware folder as described and open it with Segger Embedded Studio.
Bottleneck: Unable to find the US_probe_nRF52_firmware folder.
•	2.5.1 Setting up the Toolchain
Install the Programmer application.
Bottleneck: The Programmer cannot be downloaded because the nRF Connect apps for Windows indicated in the manual are outdated.
Bottleneck of the Third Category:
•	The user manual does not specify how to power up the transmitter part. As a result, we cannot ensure the probe is working, and the nRF52 dongle is not connected to the probe.
•	If possible, we would appreciate a detailed, step-by-step procedure for the setup process, from start to successfully measuring the A-mode and B-mode graphs.

Sergio5714, 2024-12-17:
Thank you for your feedback. Indeed, there were a couple of inaccuracies.
We updated the User Manual to address your comments. It will be available soon as a part of a new release.

Sergio5714, 2024-12-20:
We fixed this issue and merged it into the dev branch. The changes will be a part of the release 1.2.0.

Closed 2024-12-20.

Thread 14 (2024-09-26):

There's a wrong file

mushroom1224, 2024-09-26:
In wulpus-main/hw/wulpus_acquisition_pcb/docs/wulpus_acq_pcb_schematics.pdf, R2 should be connected to EN
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

Sergio5714, 2024-12-11:
Thank you for noticing and rfeporting an issue. We further investigated it and found the following:

**Issue:** EN_HV (pin 5 of the U1 DC-DC) connector is probably floating when the MSP430 is not programmed. According to the datasheet of TLV62569, it should not be left floating.
**Potential solution:** There is no need for mounting R2 (EN is controlled by the MCU). But placing a weak pull-down resistor to fix the disabled state (during booting) is necessary.

I am merging this issues in the following issue and closing this one:

https://github.com/pulp-bio/wulpus/issues/17

Closed 2024-12-11.

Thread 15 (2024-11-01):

Mating connector and pre-crimped wires

Sergio5714, 2024-11-01:
Add precrimped wires part number and mating connector part number to the User Manual

Sergio5714, 2024-12-17:
Addressed in the Rev 1.1 of the User Guide

Sergio5714, 2024-12-20:
We fixed this issue and merged the changes into the dev branch. The changes will be a part of the release 1.2.0.

Closed 2024-12-20.

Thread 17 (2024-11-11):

Power supply spikes exceeding the resistors power rating. Enable pin control of the U1

Sergio5714, 2024-11-11:
**Issue:**The power spikes on the supply line VSYS_IN may exceed the power rating of the current measurement resistors R1, R5, R6, R8, R9, R10, R11, R13.
**Potential solution:** Replacing the aforementioned resistors (1 Ohm) with 0.1 Ohm alternatives with the same footprint.

**Issue:** EN_HV (pin 5 of the U1 DC-DC) connector is probably floating when the MSP430 is not programmed. According to the datasheet of TLV62569, it should not be left floating.
**Potential solution:**  Placing a weak pull-down resistor to fix the disabled state by default.

Ethan010722, 2024-11-21:
Subject: Issue with EN_HV Pin and Missing 15V Output After Programming MSP430

Hi Sergio,

Thank you for your work on this project. I’ve encountered an issue with the HV board: after programming the MSP430, the 15V high voltage is not generated. I measured the EN_HV pin (Pin 5 of U1, TLV62569), and it shows 0V.

I’ve already tried connecting a 10k pull-up resistor to the EN_HV pin, but it didn’t resolve the issue. Could you advise on what might be causing this problem and how I could fix it?

Looking forward to your guidance!

Best regards,
Ethan

Sergio5714, 2024-12-20:
We fixed this issue and merged the changes into the dev branch. The changes will be a part of the release 1.2.0.

Closed 2024-12-20.

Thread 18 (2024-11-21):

Missing .epf File in Step 6 of Setup Instructions in page 16 of 2.3.2 Flashing the device(user manual)

EhsanNaeemi, 2024-11-21:
While following the setup instructions for the WULPUS repository, I encountered an issue at Step 6.
The file **workspace_preferences.epf**, mentioned in the instructions, is missing from the repository. Without this file, it's impossible to complete the import and proceed with the setup.
Also, A search through the repository confirms that no .epf file exists.

Expected Behavior is:
The file workspace_preferences.epf should be available in the directory ultra-low-power-ultrasound-probe/dev_msp430/ to allow for importing preferences into CCS.

Actual Behavior is:
The file is missing, making it impossible to proceed beyond Step 6.

Thanks!

Sergio5714, 2024-11-25:
@EhsanNaeemi, thank you for submitting an issue! As discussed in private chat, the way to import the project is to go:

File->import project ->select the folder.
The CCS will automatically find the project.

We will update the description in a new release of the documentation (hopefully by the end of the year) together with other fixes.

Sergio5714, 2024-12-17:
Thank you again for your feedback! I addressed the issue in the version 1.1 of the User Manual, which will be a part of a new release.

Sergio5714, 2024-12-20:
We fixed this issue and merged the changes into the dev branch. The changes will be a part of the release 1.2.0.

Closed 2024-12-20.

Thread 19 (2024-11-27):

Inquiry Regarding Connection Between Ultrasonic Transducer and Connector

Ethan010722, 2024-11-27:
Hello, Author,

First of all, thank you very much for sharing the ultrasonic collection system. I have successfully assembled most of the system. The only issue I am facing is figuring out how to connect the ultrasonic transducer to the connector. I am not entirely sure about the correct method for this connection and would appreciate any guidance or advice you could share.

Looking forward to your response. Thank you!

Sergio5714, 2024-12-03:
@Ethan010722, thank you for your question! Sorry for the delayed reply: we are currently quite busy and have delays in answering addressing the issues :)

Depending on the transducer, you might need a small adapter PCB to interface your transducer. On the HV PCB, we provide a board-to-wire connector. As outlined in the WULPUS User Manual, you would need the following components to interface it:

**Mating Connector and Pre-Crimped Wires:**
**Connector**: Hirose Electric DF52 Series
**Part Number:** DF52-16P-0.8C
**Description:** This is a 16-pin connector that mates with the WULPUS High-Voltage PCB's transducer port.

**Pre-Crimped Wires:**

**Part Number:** DF52-2832PF1571-28A9-300
**Description:** These pre-crimped wires are designed to work with the DF52 connector, enabling straightforward assembly of the transducer wiring.

For quick answers, we encourage you to try our ChatGPT bot that can help you to navigate the WULPUS User Manual:
https://chatgpt.com/g/g-XJs5YGjTh-wulpus-guide-assistant

Please let me know if I answered your question.

Ethan010722, 2024-12-03:
@Sergio5714
Hi Sergio,

Thank you so much for your detailed response! I really appreciate your help. Your explanation and the provided information have resolved my issue.

Additionally, I would like to inquire if your ultrasonic system supports M-mode (Motion mode)?

Thank you again for your assistance!

Best regards,
Ethan

Ethan010722, 2024-12-04:
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
Hello surgio,

I have connected the ultrasonic transducer to the board, but I don't know why there is almost no signal. I'm not sure where the problem lies, so I am seeking your advice.

Thank you very much for your help.

Best regards,
Ethan

Sergio5714, 2024-12-04:
Hello @Ethan010722 , Could you please redirect your questions to the following discussion?
https://github.com/pulp-bio/wulpus/discussions/20

I am closing this issue and will be happy to reply in aseparate discussion to keep the Issues cleaner.

Closed 2024-12-04.

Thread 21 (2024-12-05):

Missing ground plane for microstrip

MilosHirsl, 2024-12-05:
According to the datasheet of the ANT-2.45-CHP-T antenna (https://www.mouser.ch/datasheet/2/418/9/ENG_DS_L9000014_01_C-3238928.pdf), the ground plane beneath should cover the trace leading up to the antenna's feed termination pin in order to form a proper microstrip. On the acquisition board this is not the case:

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

The trace between the antenna and R22 (NetE1_1) does not have a ground plane underneath.

Sergio5714, 2024-12-10:
Thank you, @MilosHirsl  for debugging the probes and reporting the problem with the antenna layout. We are going to fix this in the next HW review round.

Closed 2025-01-21.

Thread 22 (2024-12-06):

User guide corrections

CedricHirschi, 2024-12-06:
I have come across some points in the user guide where some corrections could be made:

- The USS configuration displayed in Figure 5.2 includes a wrong value: `DC-DC turn on time [us]` should be `100` for the actual time in microseconds, not this legacy ticks number. (Same goes for all USS config GUI screenshots actually)
- Also, I think we should clarify that the channel numbers 1-8 in the schematic correspond to the IDs 0-7 in the GUI as a seperate Note.
  - The TX/RX config for pseudo-B-mode in Table 4.1 for example includes such an error, since the TX channels are specified as `0-8`, which would rather be `0-7`.
  - The waterbath demo also mentions to `please wire the transducer to channel 8`, and although this is mentioned later as `channel number 8 (id = 7)`, this should be uniform in the whole user guide.

These are some more suggestions:
- Could we add more example measurements, even though they may use transducers that are not readily available?
- Add an errata part with the issues we have found up until now? Also manufacturing challenges?

Sergio5714, 2024-12-20:
We fixed this issue and merged the changes into the dev branch. The changes will be a part of the release 1.2.0.

Closed 2024-12-20.

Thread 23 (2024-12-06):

Alternatives for compilation

CedricHirschi, 2024-12-06:
I think adding a guide for compiling the projects with a Makefile would be quite nice.
In the case of the nRF52 projects, this could be an alternative to installing Segger Embedded Studio, and in the case of the MSP430 projects it could still simplify project building.

For this, we would have to supply the correct Makefiles, which I have already partly done in [my fork](https://github.com/CedricHirschi/wulpus/commit/a02a4caa7530c1ddec5d98f575626afab9dc6ef7).

For flashing, some alternate tools like [nrfjprog](https://www.nordicsemi.com/Products/Development-tools/nRF-Command-Line-Tools) and [MSP430-Flasher](https://www.ti.com/tool/MSP430-FLASHER) could be used.

Although the guides for the existing IDEs may be more fool proof for both sides, I think the effort of providing these alternatives may be small for the value it gives.

CedricHirschi, 2024-12-06:
Also, for the MSP firmware, there now exists an [online solution](https://dev.ti.com/ide). This could also be very nice for an easier start. Importing the current project as is works for me.

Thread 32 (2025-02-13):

Vias close to the pads of the component C40 of the Acquisition PCB

Sergio5714, 2025-02-13:
**Affected HW Revision:** 1.2.1  (Acquisition PCB)

** Description**: Two vias are touching the pads of the capacitor C40 of the Acquisition PCB. Although HW batch from Release 1.1.0 did not show any problems, shifting the vias further from the pads would be cleaner to avoid any potential solder wicking during Assembly.

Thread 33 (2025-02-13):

Via size on the nRF52 ground pad of the Acqusition PCB

Sergio5714, 2025-02-13:
**Affected HW Revision:** 1.2.1  (Acquisition PCB)

**Description:** The vias of the ground pad of the nRF52 IC are 0.2 mm (hole) and 0.5 mm (diameter). Since all other vias has hole equal 0.3 mm, these few vias just increase the production price. The constraints can be relaxed by increasing the hole size to 0.3 mm.

Closed 2025-04-04.

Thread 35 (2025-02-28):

MSP430 Fails to Boot Firmware After Random Event (Possibly ESD Shock)

Sergio5714, 2025-02-28:
**Affected HW/FW Revision:** 1.0.0 - 1.2.1 (Acquisition PCB)

**Description:** The MSP430 microcontroller stops booting firmware after an unpredictable event, possibly due to an ESD shock.

**Symptoms:**
- The probe successfully establishes communication with the dongle.
- However, when starting the acquisition, the process hangs.

**Recovery Steps:**
- After connecting the probe to the debugger, flashing is initially not possible (memory erase fails).
- However, after entering Debug mode, flashing becomes possible again.

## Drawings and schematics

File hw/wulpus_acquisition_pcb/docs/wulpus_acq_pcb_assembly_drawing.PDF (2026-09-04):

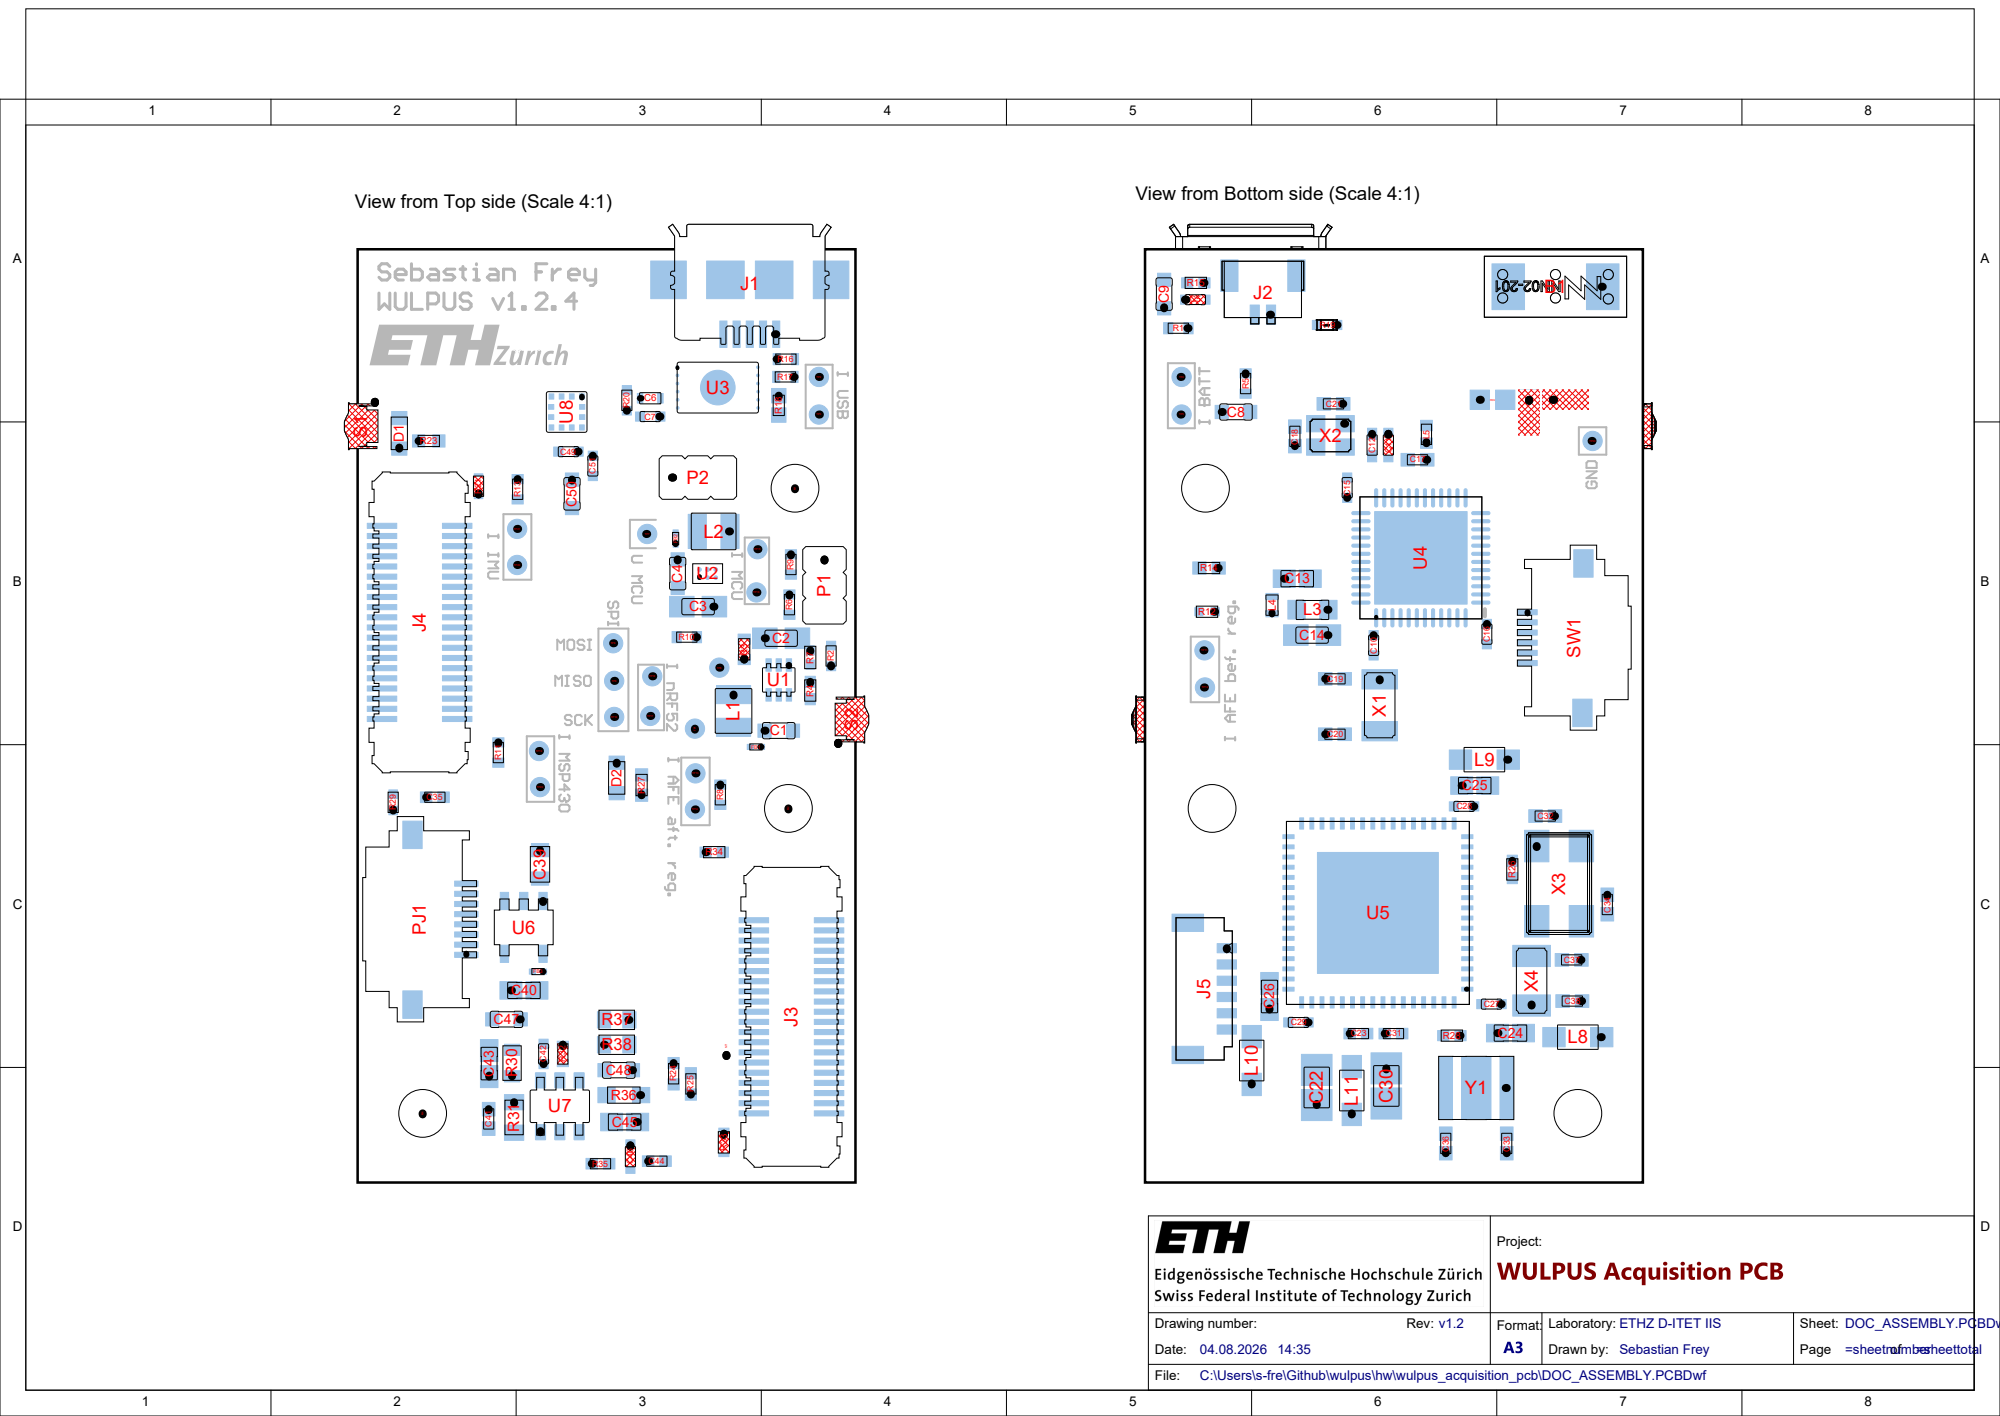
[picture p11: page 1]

View from Bottom side (Scale 4:1)

View from Top side (Scale 4:1)

Laboratory: ETHZ D-ITET IIS
Drawn by:

Sheet:
Page =sheetnumber of =sheettotal

C:\Users\s-fre\Github\wulpus\hw\wulpus_acquisition_pcb\DOC_ASSEMBLY.PCBDwf

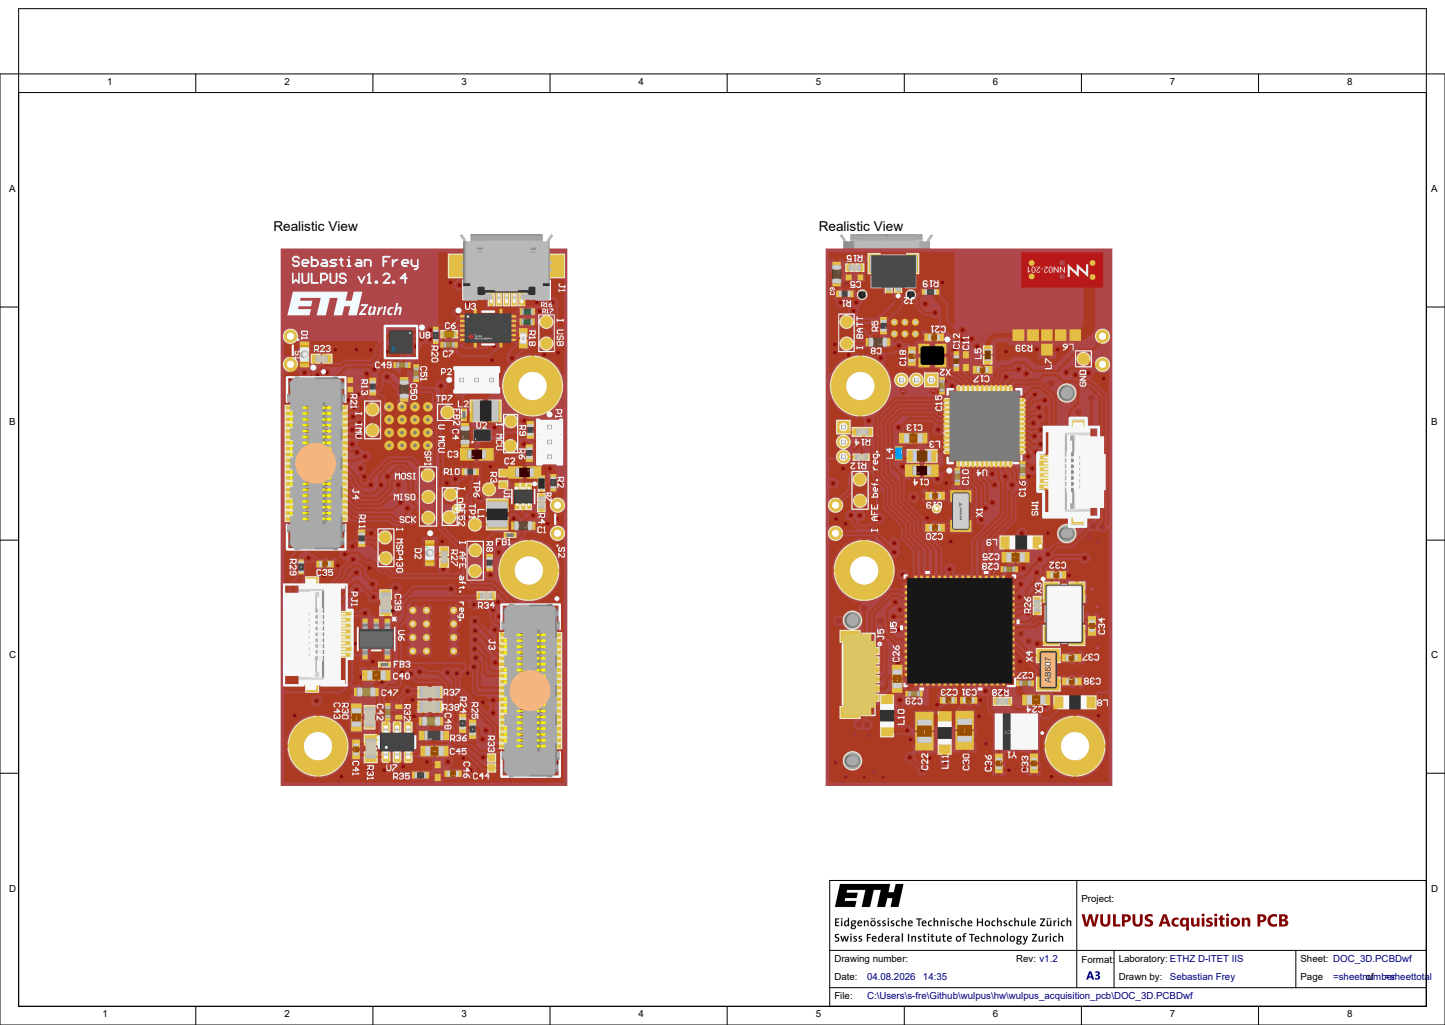
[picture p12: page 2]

Project:

Drawing number: Rev: v1.2 Date: 04.08.2026 14:35 | Format: | Laboratory: ETHZ D-ITET IIS Drawn by: Sebastian Frey | Sheet: DOC_3D.PCBDwf Page =sheetnumber of =sheettotal

C:\Users\s-fre\Github\wulpus\hw\wulpus_acquisition_pcb\DOC_3D.PCBDwf

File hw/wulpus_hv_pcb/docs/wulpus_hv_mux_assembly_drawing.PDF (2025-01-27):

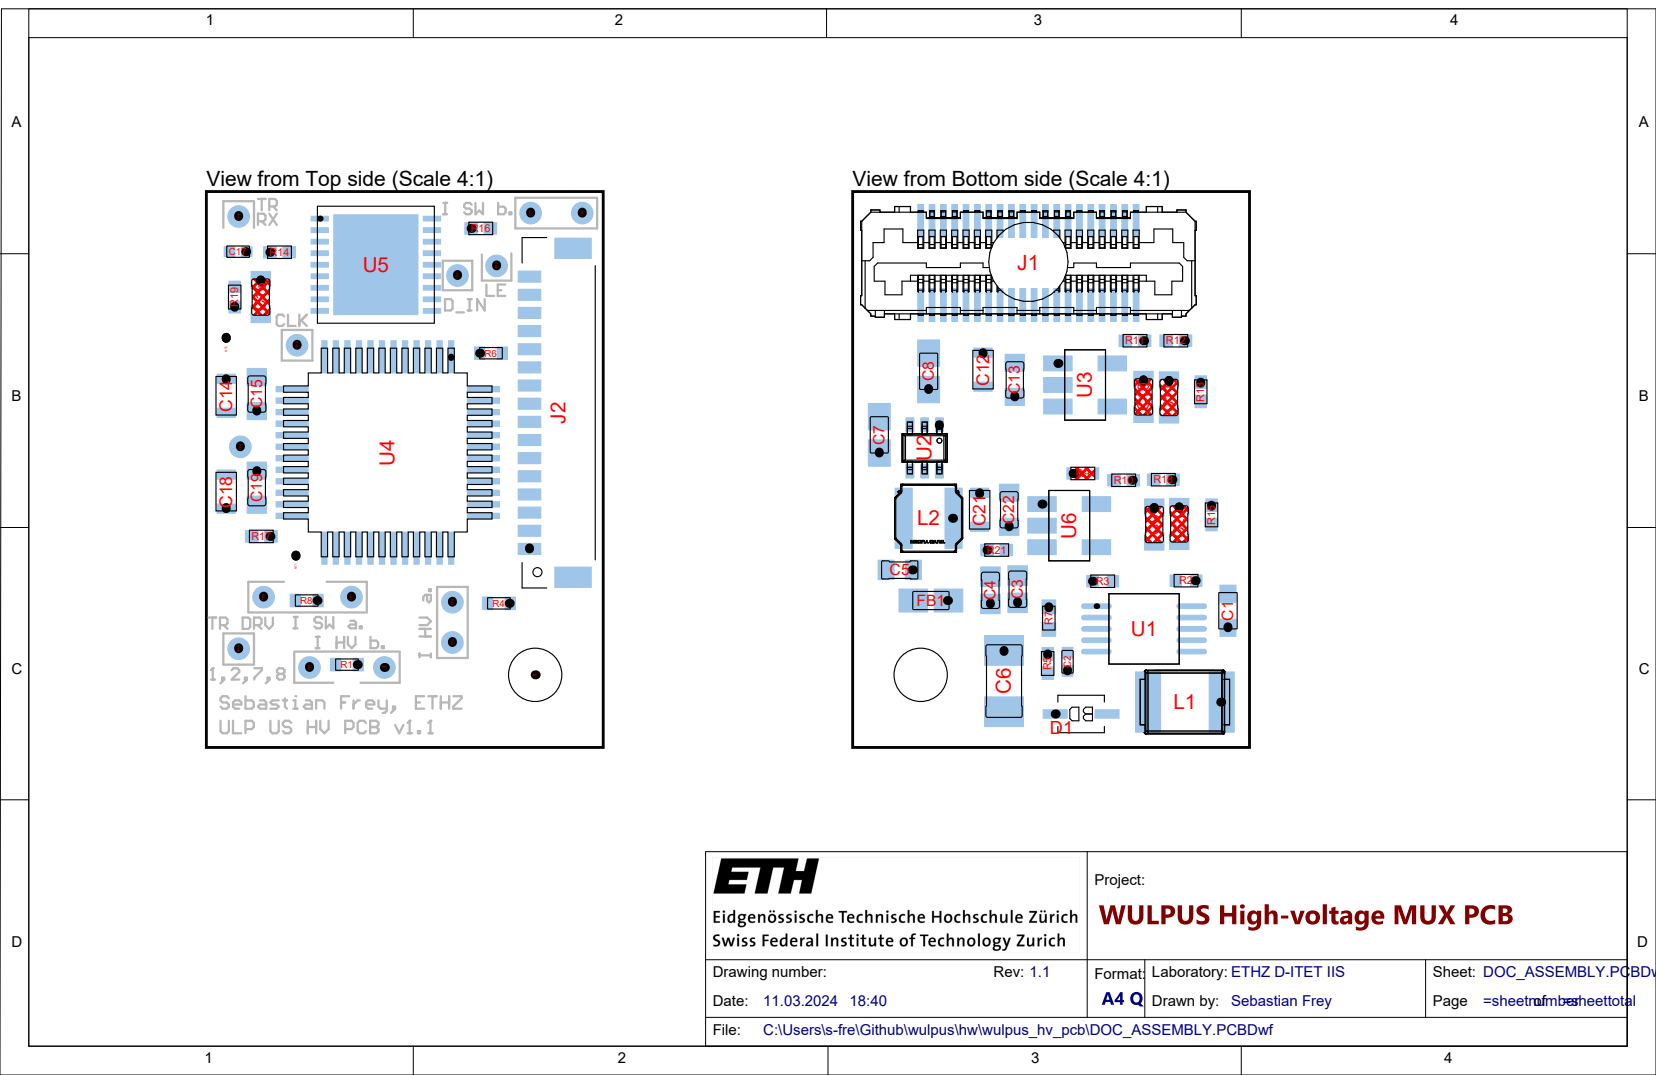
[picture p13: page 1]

View from Top side (Scale 4:1)

View from Bottom side (Scale 4:1)

Laboratory: ETHZ D-ITET IIS
Drawn by:

Sheet:
Page =sheetnumber of =sheettotal

C:\Users\s-fre\Github\wulpus\hw\wulpus_hv_pcb\DOC_ASSEMBLY.PCBDwf

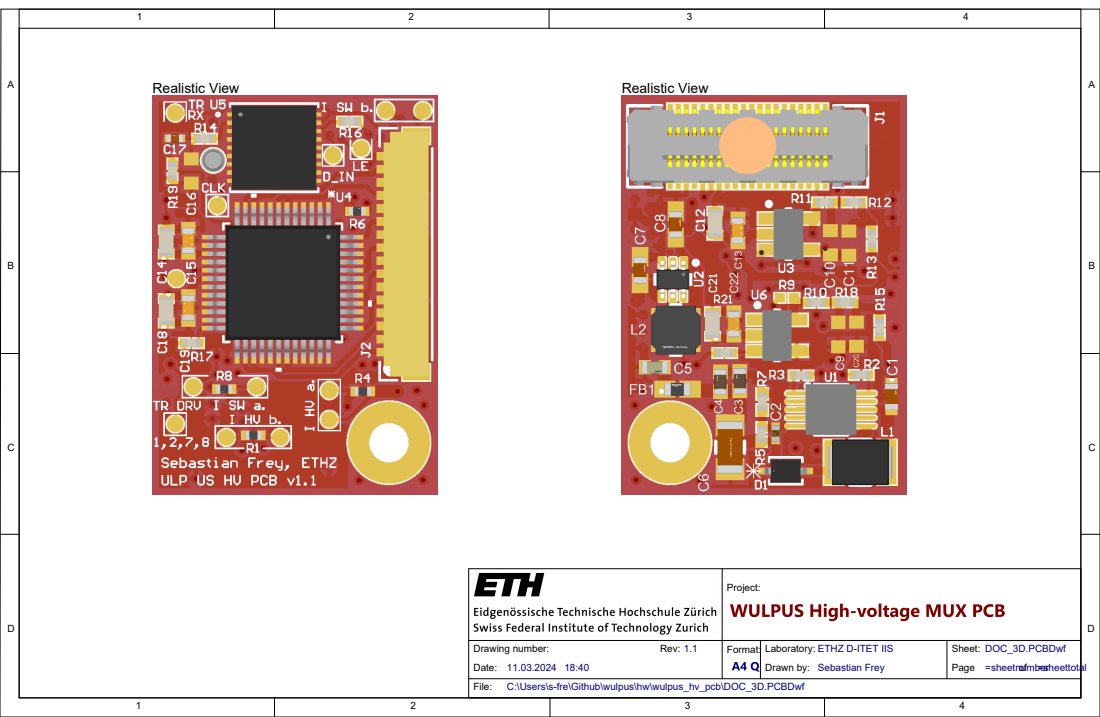
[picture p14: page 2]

Project:

Drawing number: Rev: 1.1 Date: 11.03.2024 18:40 | Format: | Laboratory: ETHZ D-ITET IIS Drawn by: Sebastian Frey | Sheet: DOC_3D.PCBDwf Page =sheetnumber of =sheettotal

C:\Users\s-fre\Github\wulpus\hw\wulpus_hv_pcb\DOC_3D.PCBDwf

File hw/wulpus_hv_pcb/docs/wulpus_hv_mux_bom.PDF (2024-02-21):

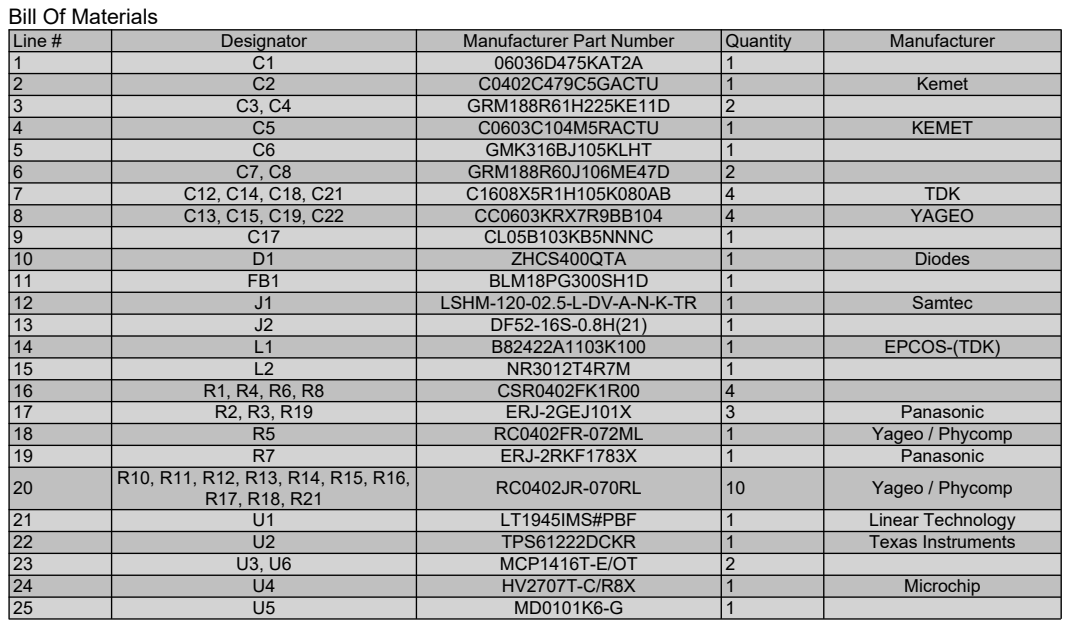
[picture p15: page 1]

Line # | Designator | Manufacturer Part Number | Quantity | Manufacturer
1 | C1 | 06036D475KAT2A | 1
2 | C2 | C0402C479C5GACTU | 1 | Kemet
3 | C3, C4 | GRM188R61H225KE11D | 2
4 | C5 | C0603C104M5RACTU | 1 | KEMET
5 | C6 | GMK316BJ105KLHT | 1
6 | C7, C8 | GRM188R60J106ME47D | 2
7 | C12, C14, C18, C21 | C1608X5R1H105K080AB | 4 | TDK

9 | C17 | CL05B103KB5NNNC | 1
10 | D1 | ZHCS400QTA | 1 | Diodes
11 | FB1 | BLM18PG300SH1D | 1
12 | J1 | LSHM-120-02.5-L-DV-A-N-K-TR | 1 | Samtec
13 | J2 | DF52-16S-0.8H(21) | 1
14 | L1 | B82422A1103K100 | 1 | EPCOS-(TDK)
15 | L2 | NR3012T4R7M | 1
16 | R1, R4, R6, R8 | CSR0402FK1R00 | 4
17 | R2, R3, R19 | ERJ-2GEJ101X | 3 | Panasonic
18 | R5 | RC0402FR-072ML | 1 | Yageo / Phycomp
19 | R7 | ERJ-2RKF1783X | 1 | Panasonic
20 | R10, R11, R12, R13, R14, R15, R16, R17, R18, R21 | RC0402JR-070RL | 10 | Yageo / Phycomp

21 | U1 | LT1945IMS#PBF | 1 | Linear Technology

23 | U3, U6 | MCP1416T-E/OT | 2
24 | U4 | HV2707T-C/R8X | 1 | Microchip
25 | U5 | MD0101K6-G | 1

Project:

Drawing number: * Rev: 1.1 Date: 27.11.2023 23:01 | Format: | Laboratory: ETHZ D-ITET IIS Drawn by: Sebastian Frey | Sheet: DOC_BOM.PCBDwf Page =sheetnumber of =sheettotal

C:\Users\s-fre\Github\wulpus\hw\wulpus_hv_pcb\DOC_BOM.PCBDwf

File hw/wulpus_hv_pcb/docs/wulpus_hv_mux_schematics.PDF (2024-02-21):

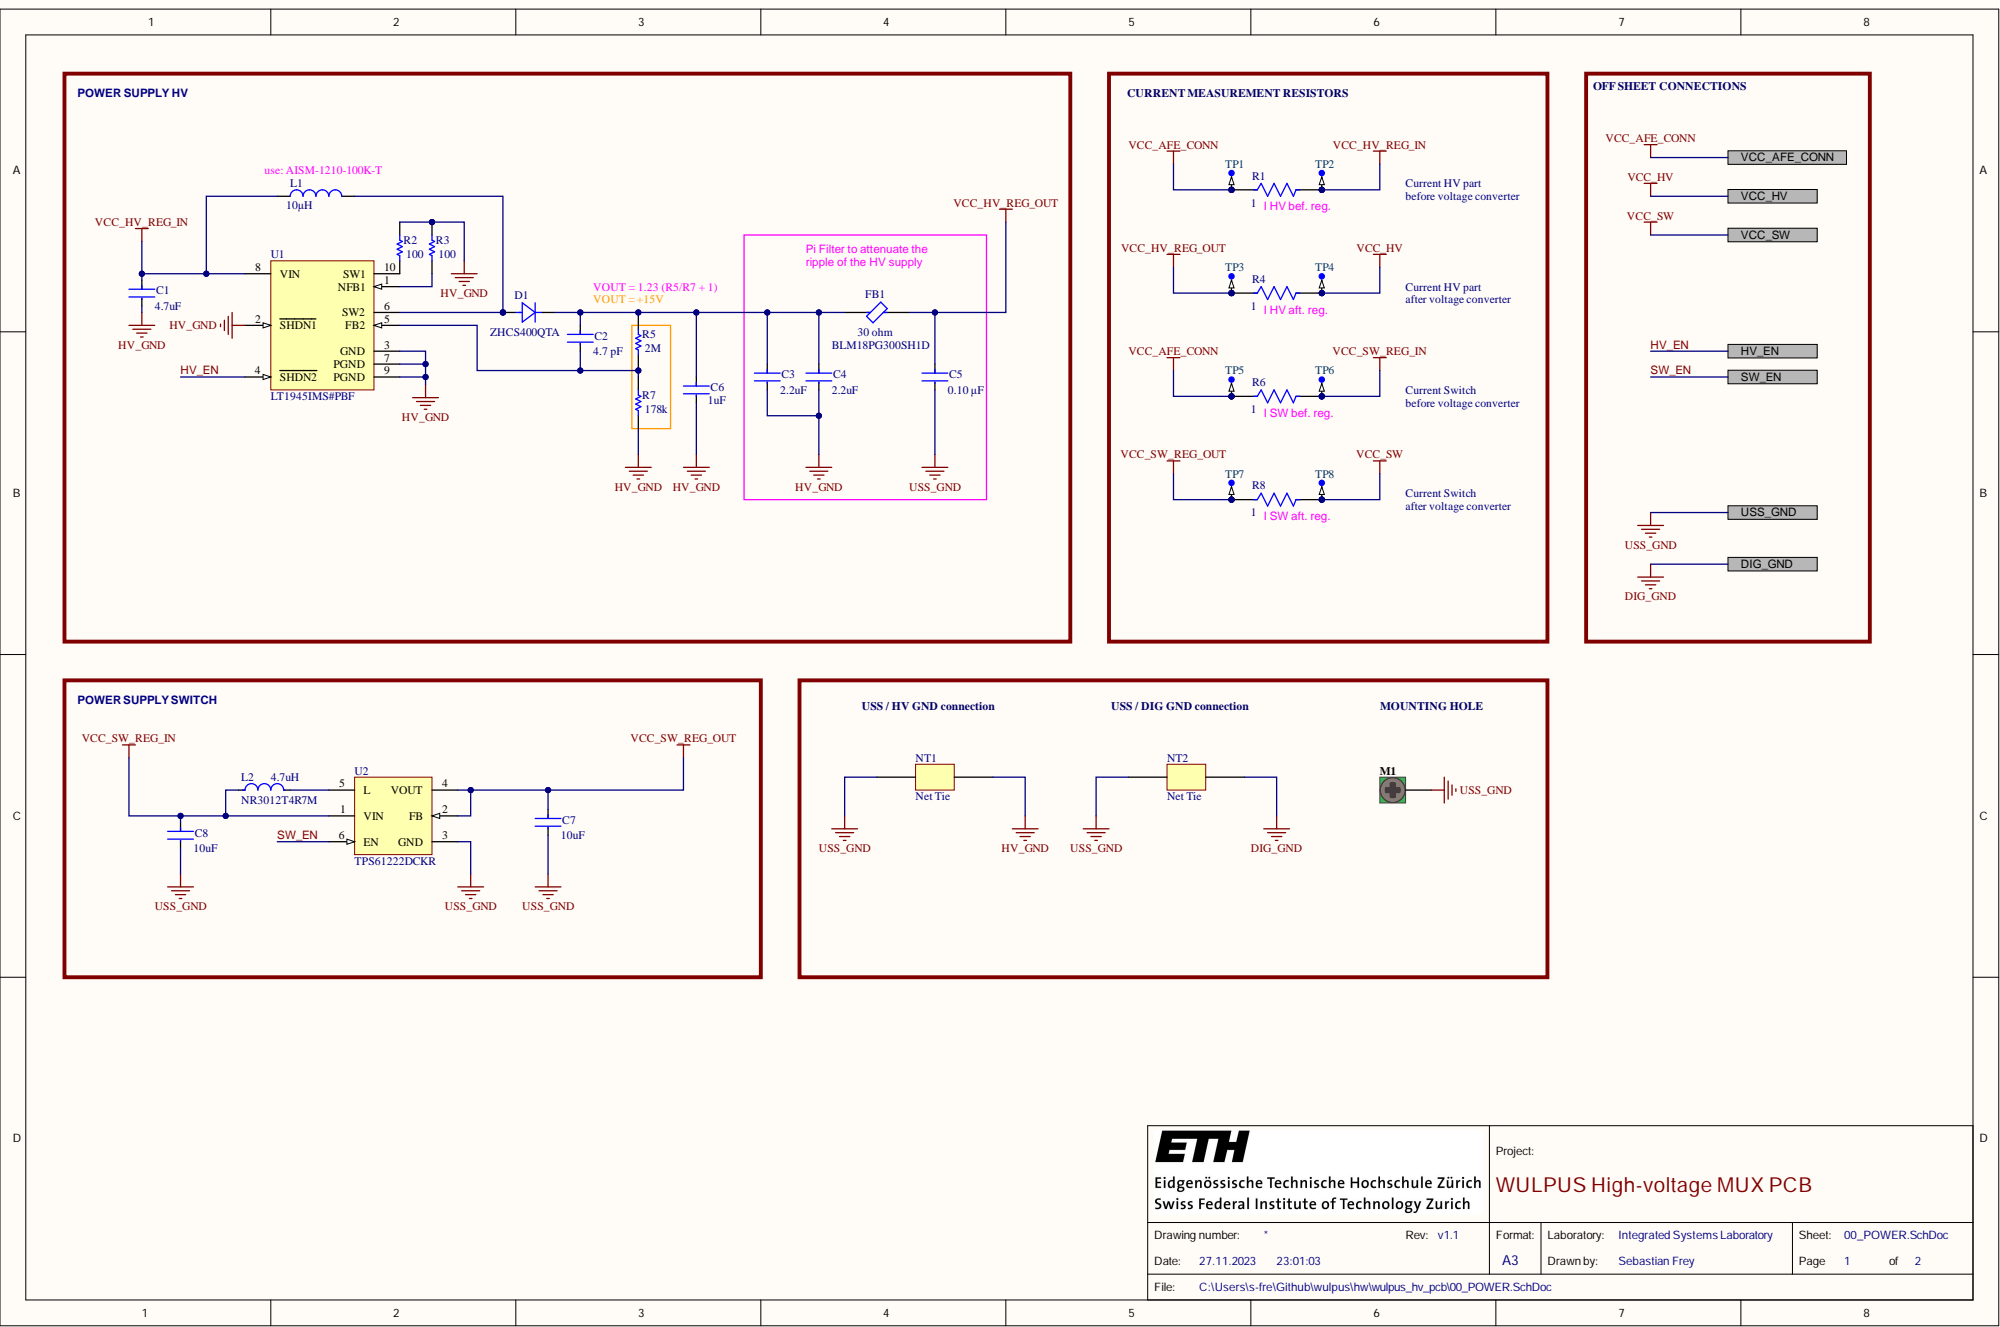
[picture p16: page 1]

Pi Filter to attenuate the
ripple of the HV supply

USS / HV GND connection

USS / DIG GND connection

Project: WULPUS High-voltage MUX PCB

Drawing number: * Rev: v1.1 Date: 27.11.2023 23:01:03 | Format: A3 | Laboratory: Integrated Systems Laboratory Drawn by: Sebastian Frey | Sheet: 00_POWER.SchDoc Page 1 of 2

C:\Users\s-fre\Github\wulpus\hw\wulpus_hv_pcb\00_POWER.SchDoc

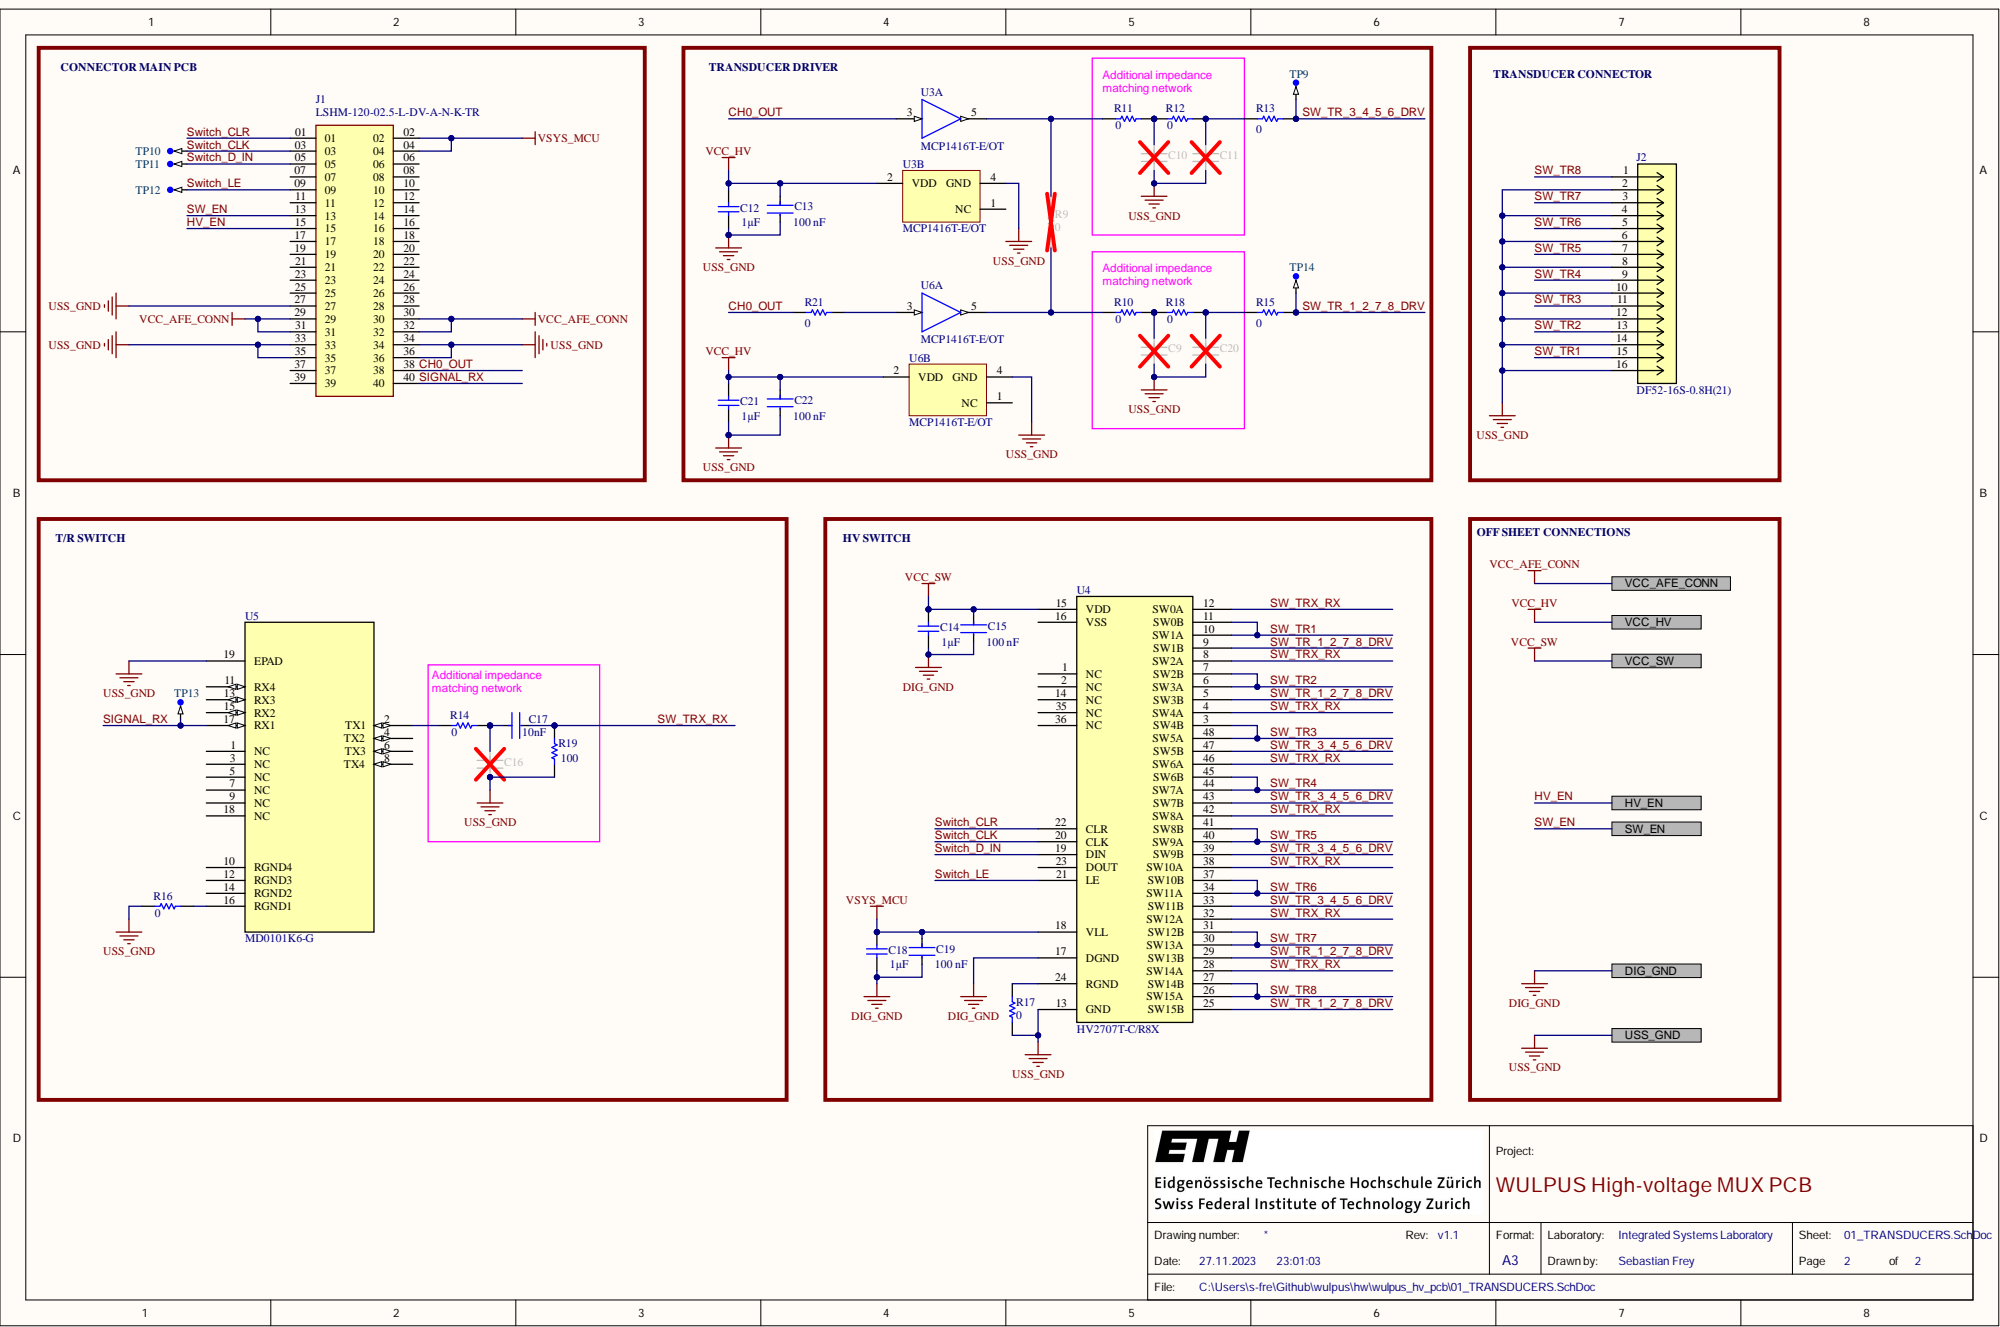
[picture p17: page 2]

Project: WULPUS High-voltage MUX PCB

Drawing number: * Rev: v1.1 Date: 27.11.2023 23:01:03 | Format: A3 | Laboratory: Integrated Systems Laboratory Drawn by: Sebastian Frey | Sheet: 01_TRANSDUCERS.SchDoc Page 2 of 2

C:\Users\s-fre\Github\wulpus\hw\wulpus_hv_pcb\01_TRANSDUCERS.SchDoc

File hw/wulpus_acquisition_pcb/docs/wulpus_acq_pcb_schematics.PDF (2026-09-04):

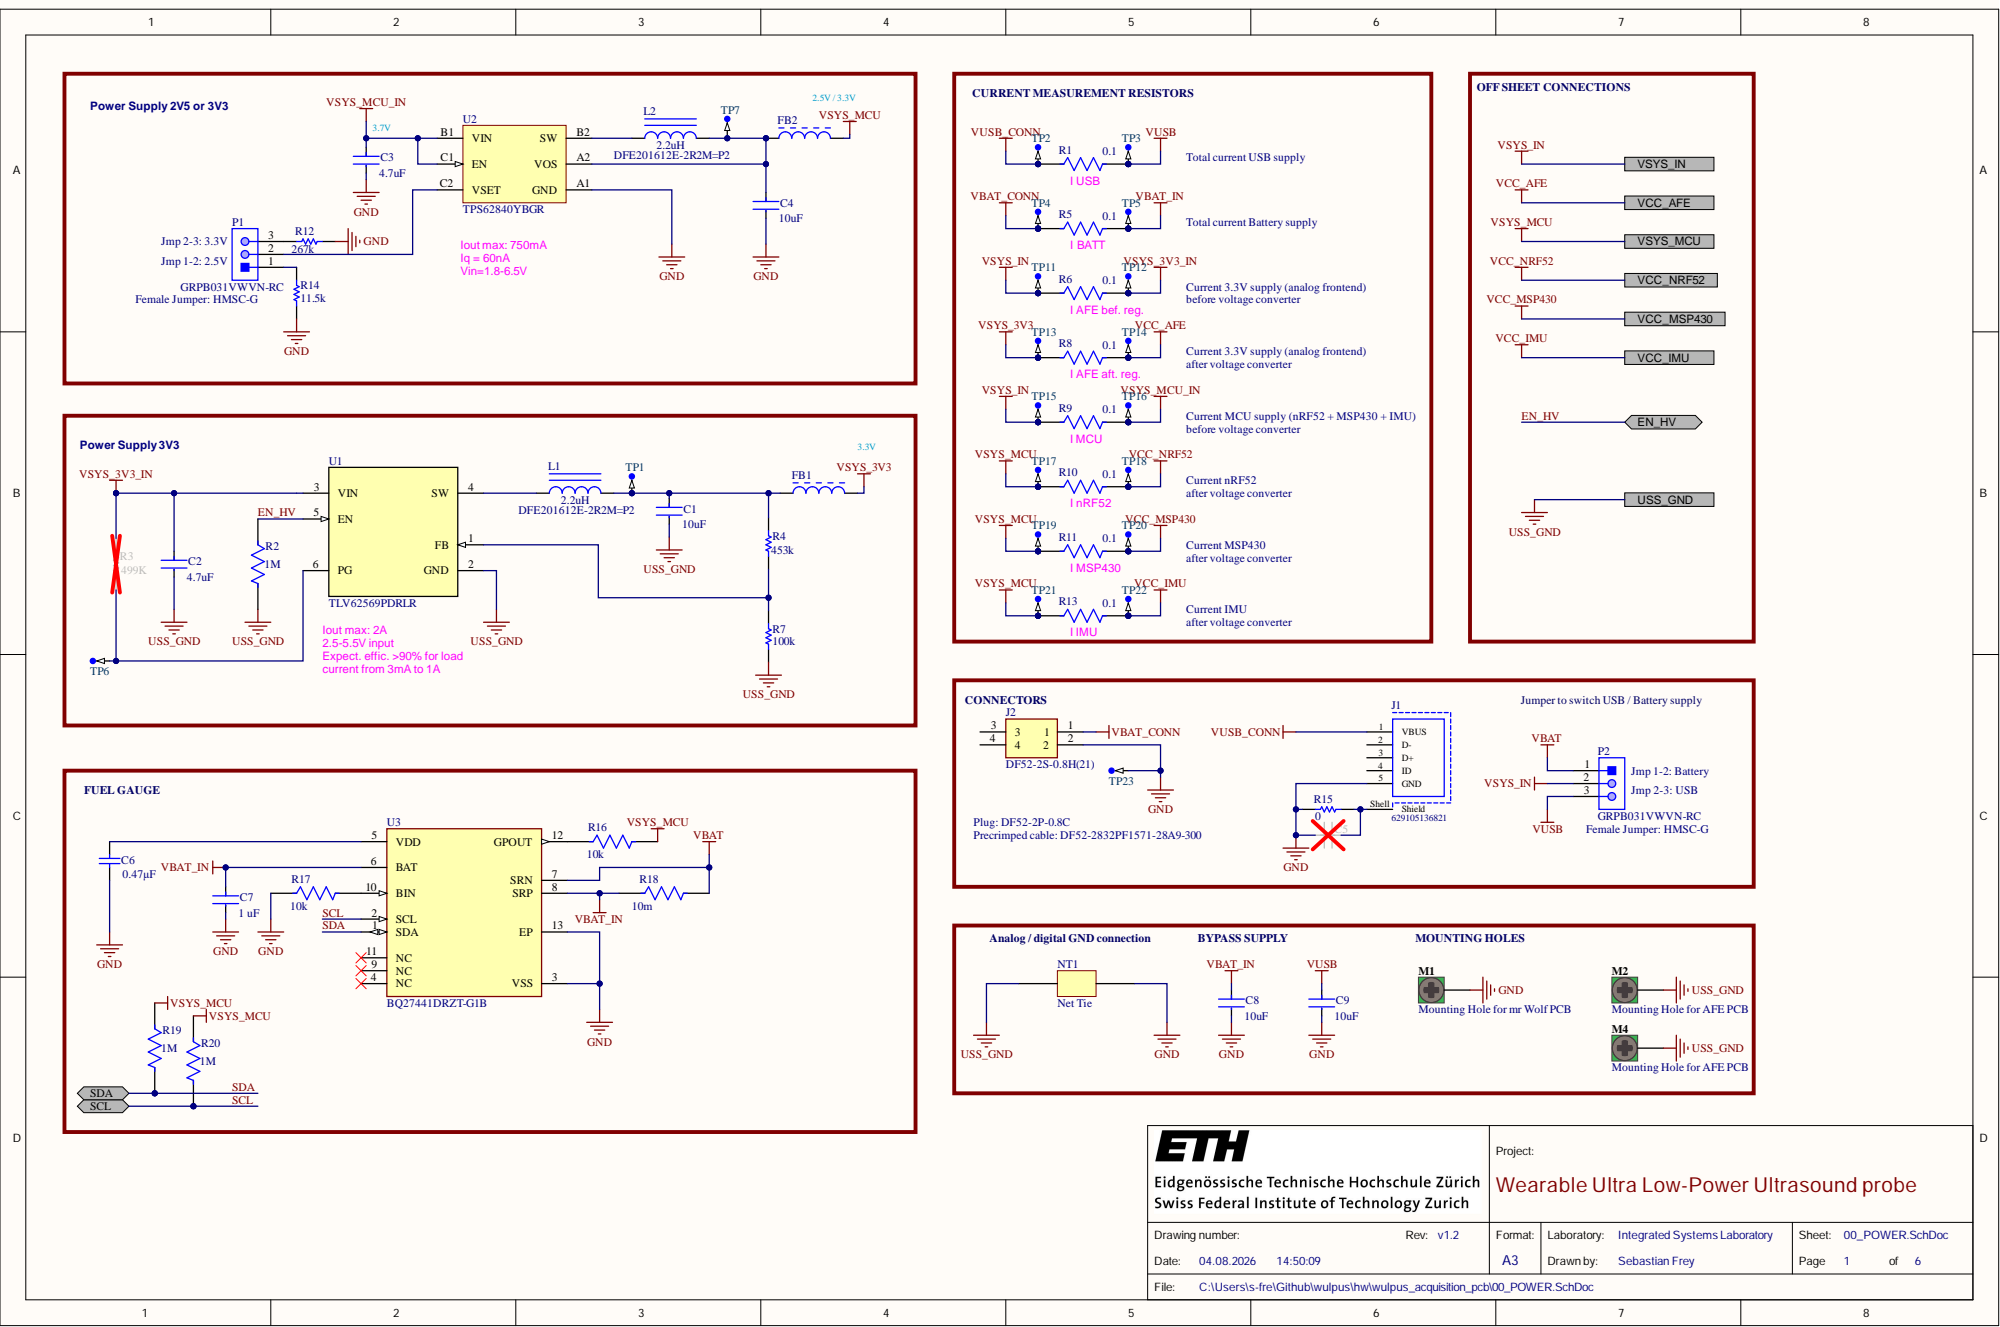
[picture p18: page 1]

Proje c t: W e a ra b l e U l tra L o w-P o we r U l tra s o u n d p ro b e

Drawing num b r: v D a te | Form t: A | Laborato ry Integrated Sy tem s Labo ra to Drawn by Sebas tian F re y | Shee 00_POW E Pag of

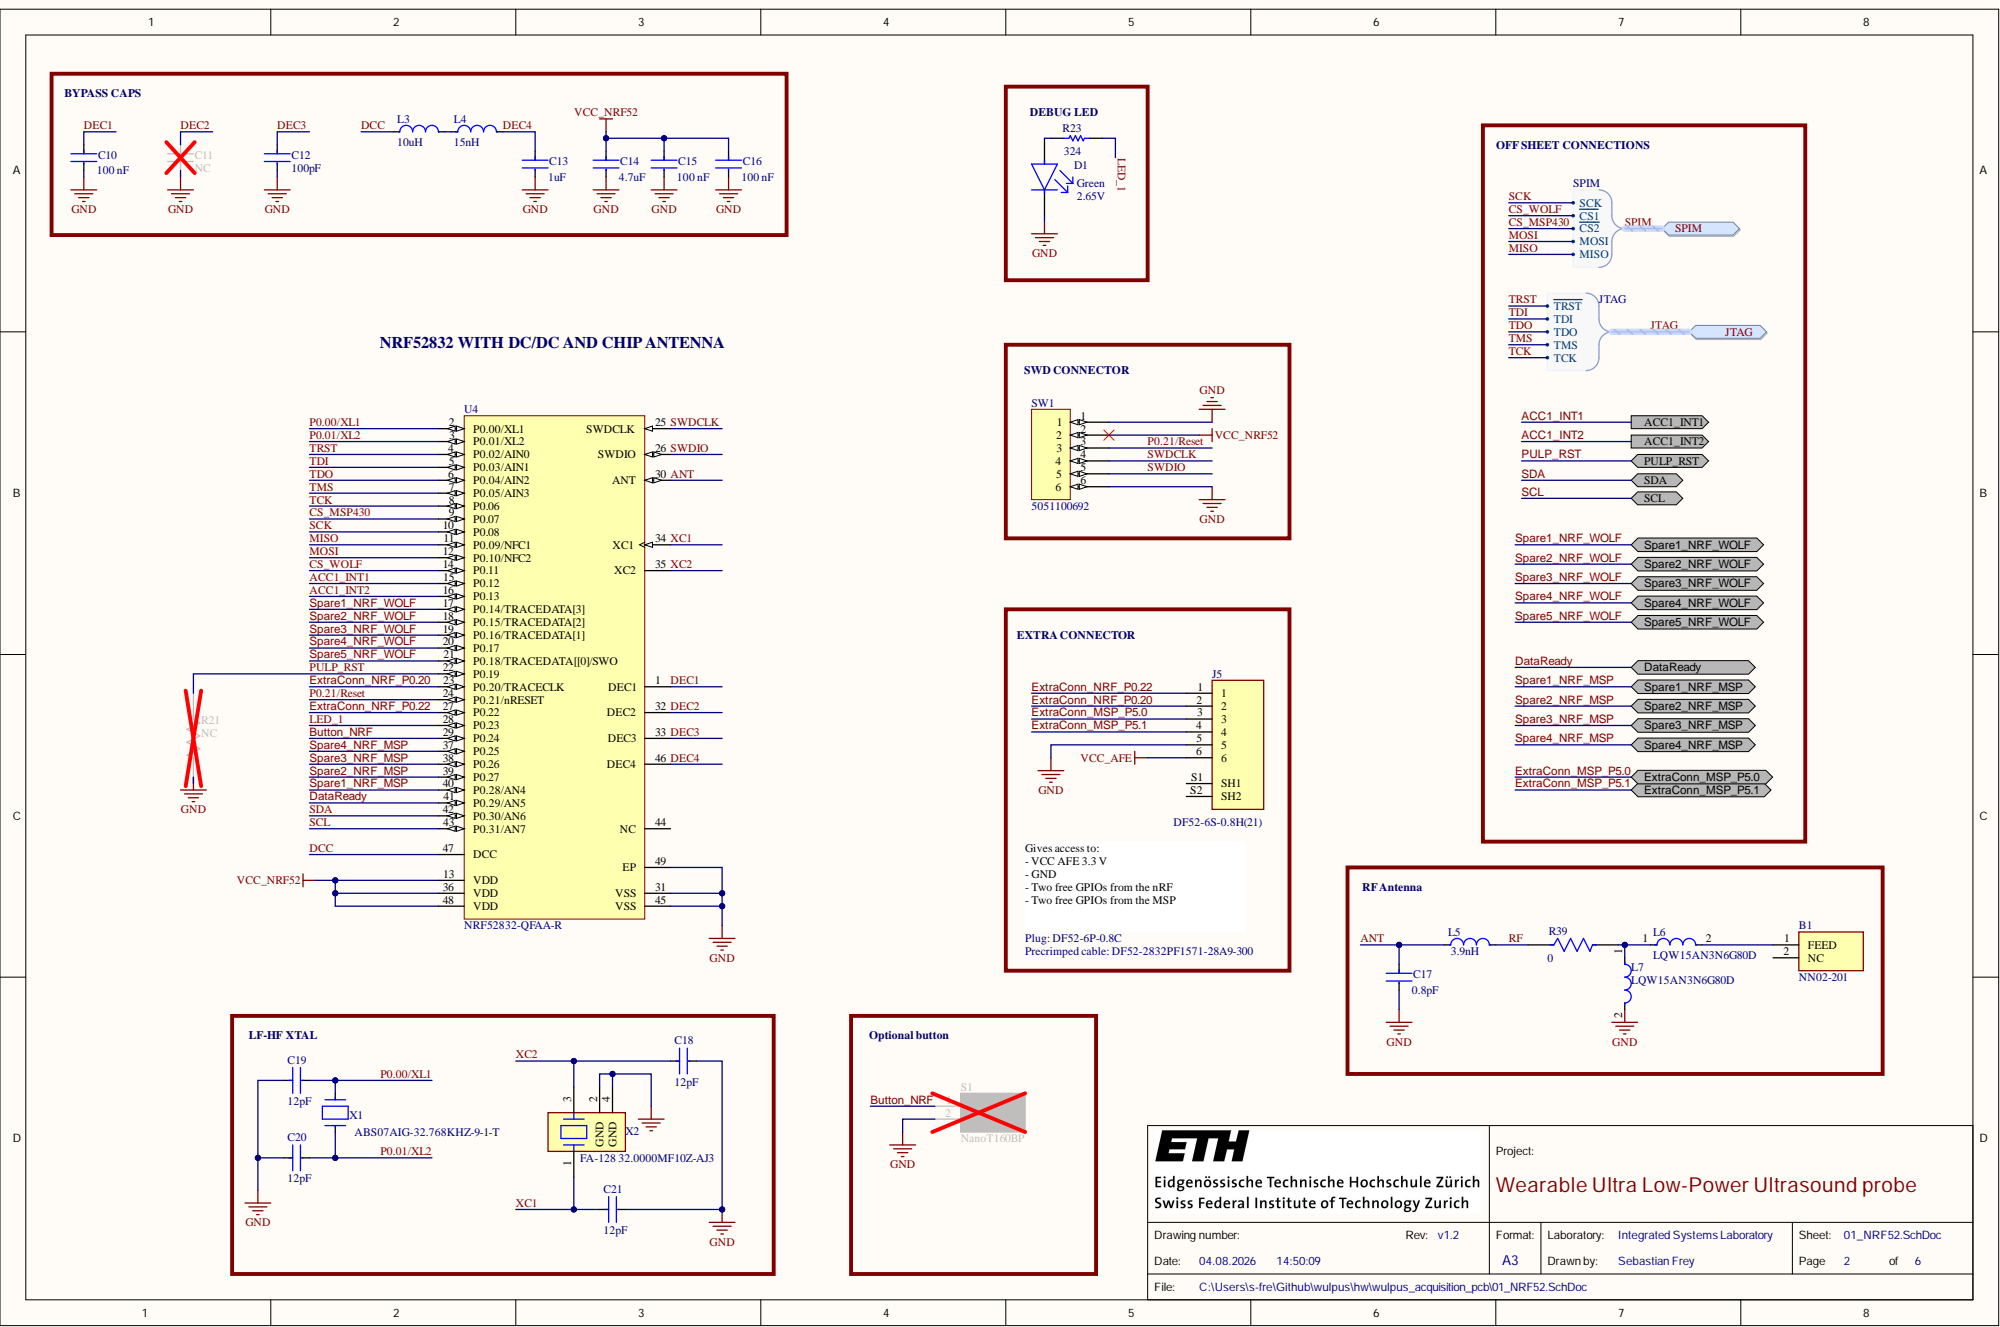
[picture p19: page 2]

3 6
4 8 | | 4 5

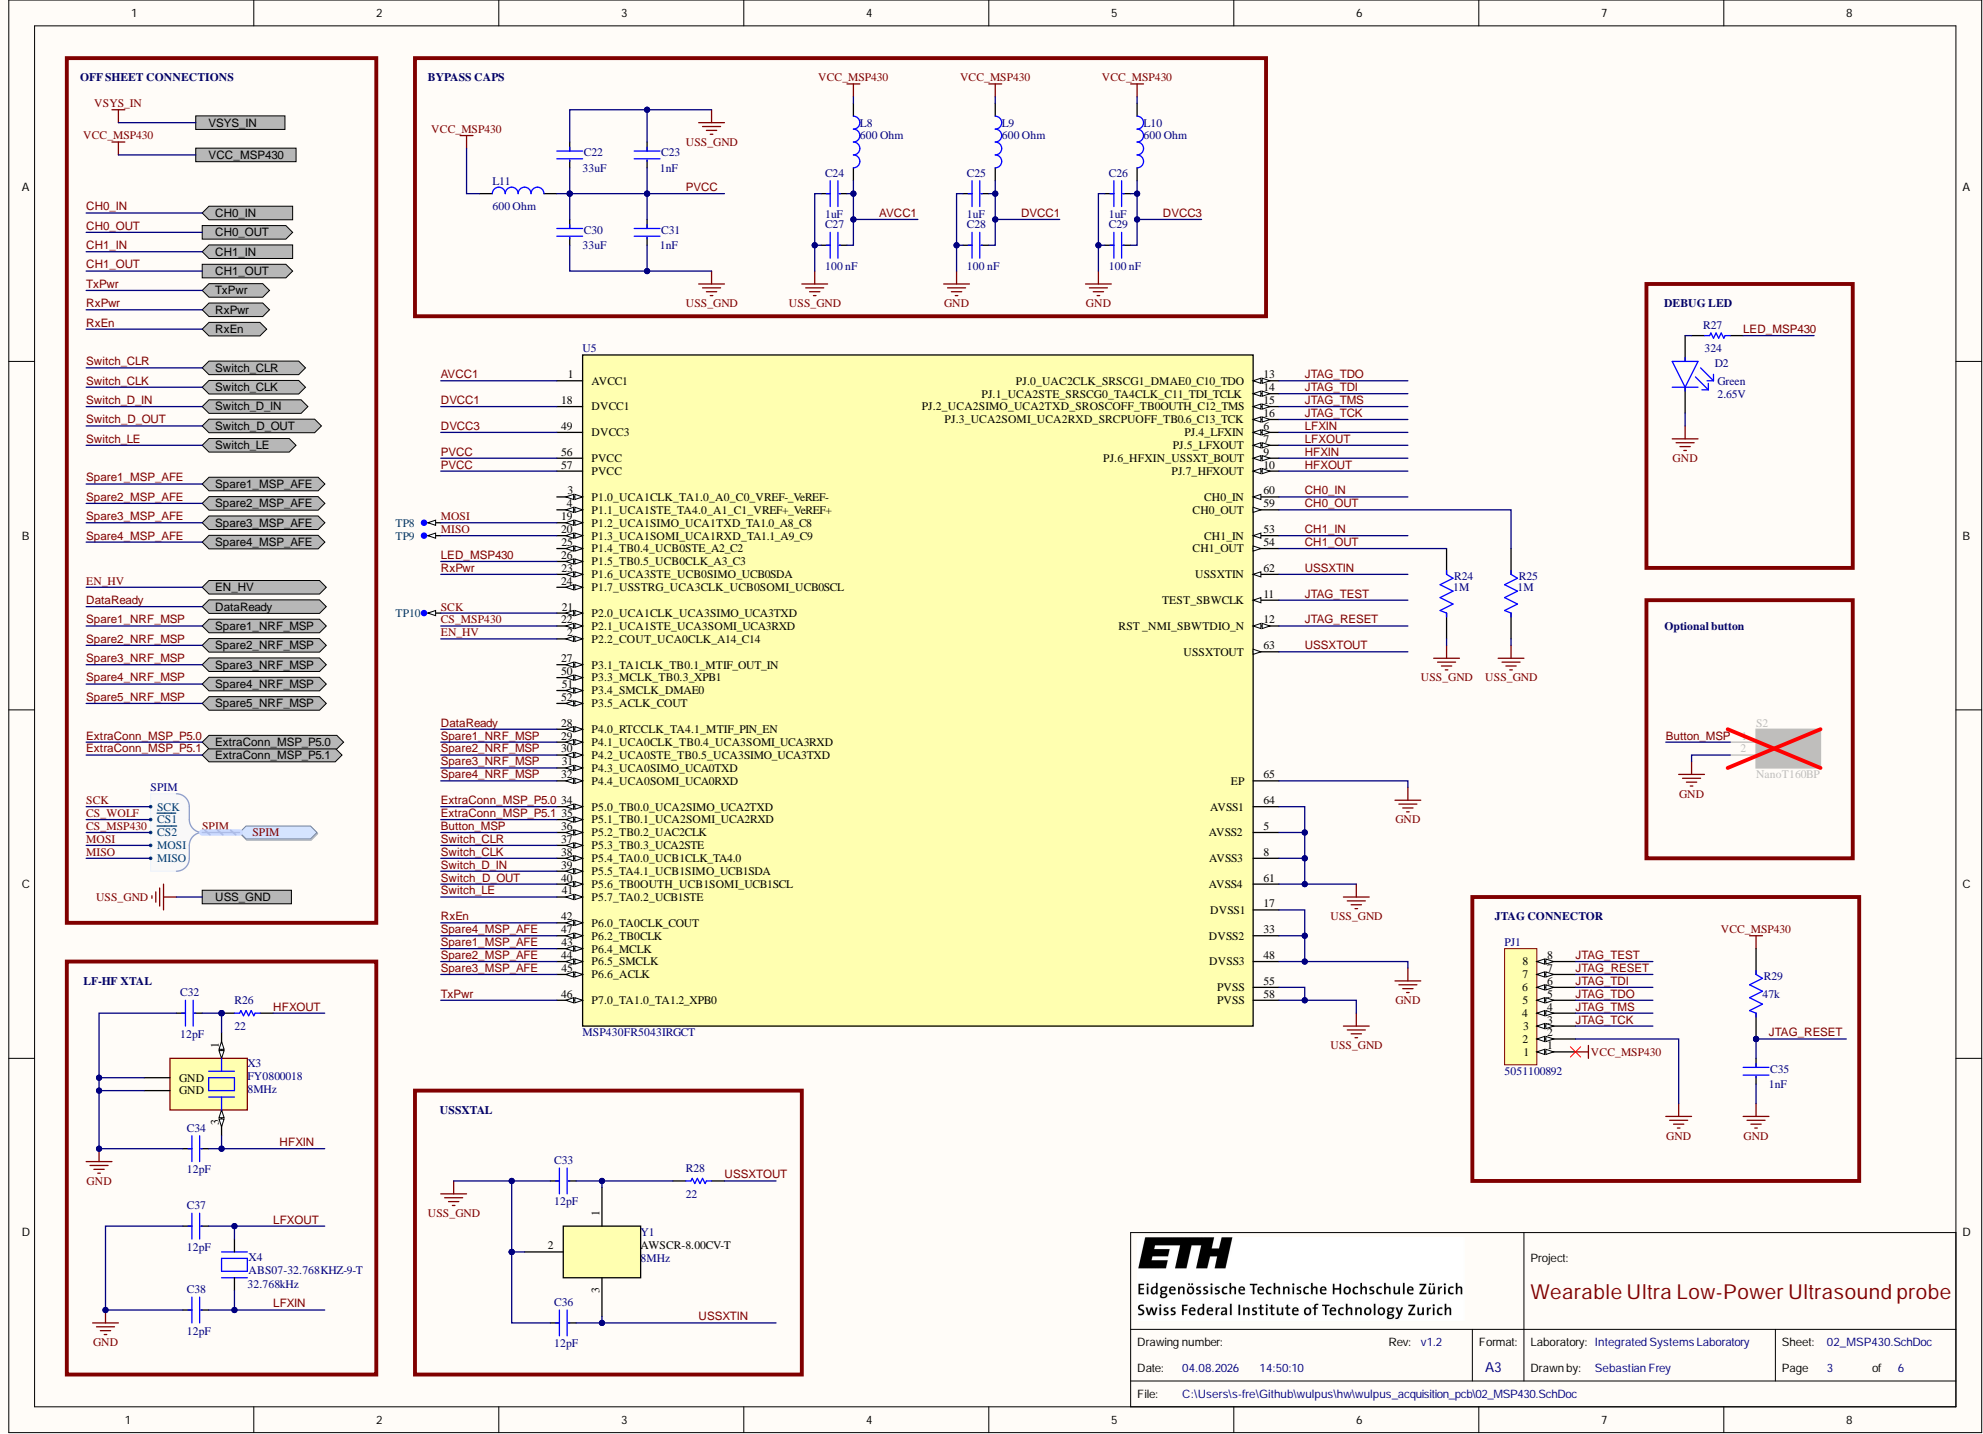
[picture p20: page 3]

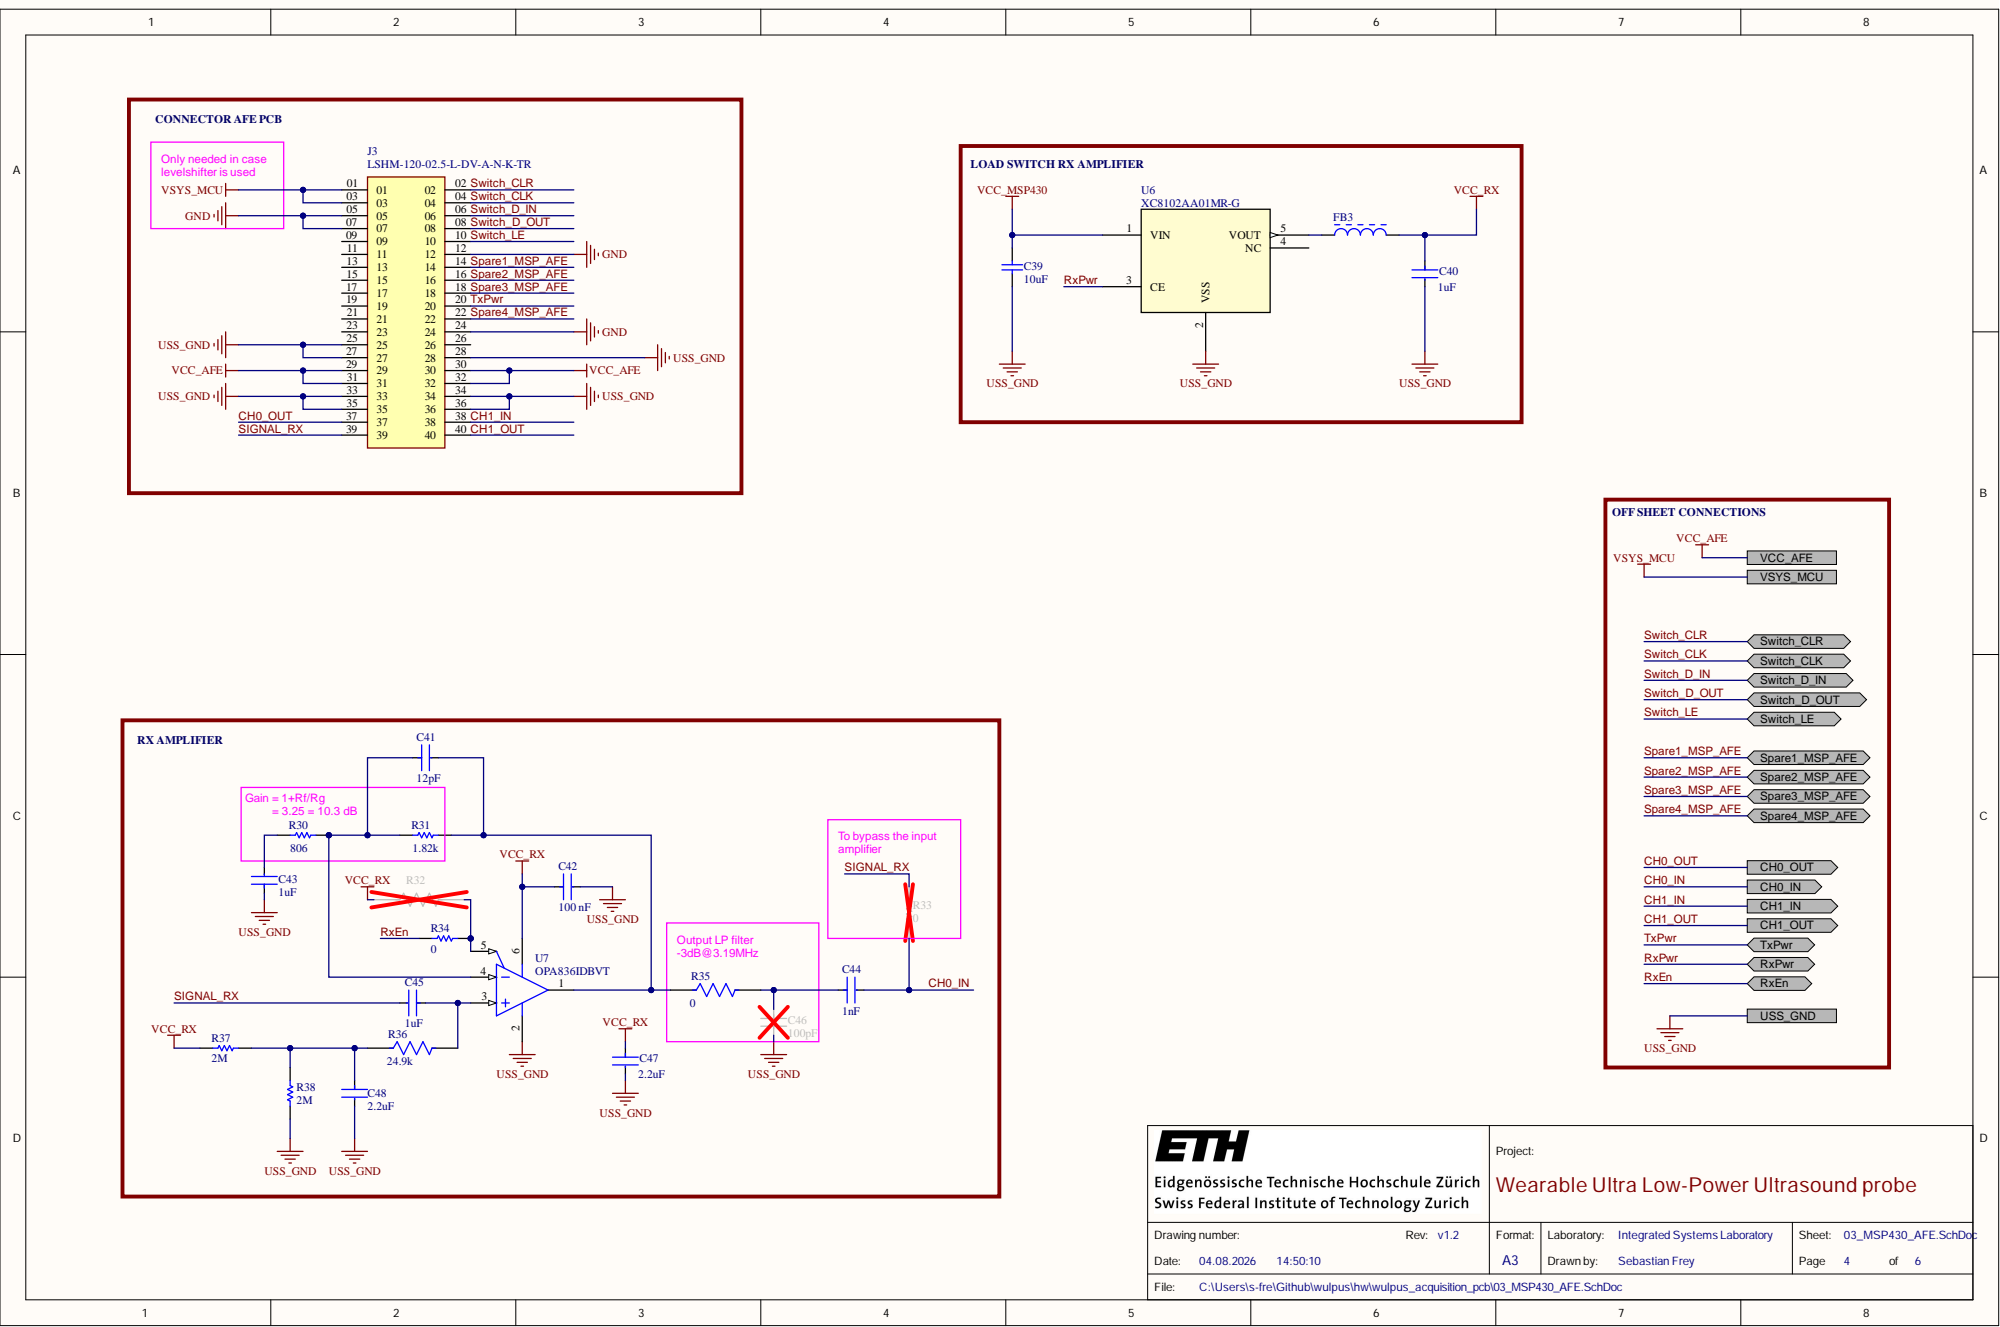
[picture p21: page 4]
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

03_MSP430_A E

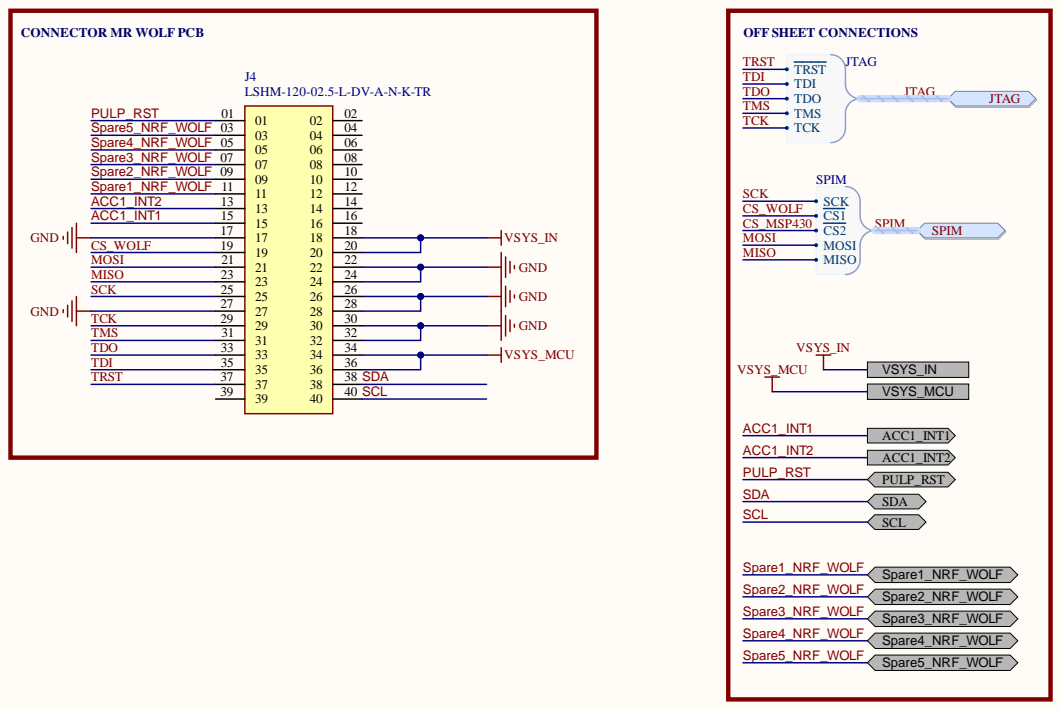
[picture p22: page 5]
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


Project: Wearable Ultra Low-Power Ultrasound probe

Drawing number: Rev: v1.2 Date: 04.08.2026 14:50:10 | Format: A3 | Laboratory: Integrated Systems Laboratory Drawn by: Sebastian Frey | Sheet: 05_IMU.SchDoc Page 6 of 6

C:\Users\s-fre\Github\wulpus\hw\wulpus_acquisition_pcb\05_IMU.SchDoc

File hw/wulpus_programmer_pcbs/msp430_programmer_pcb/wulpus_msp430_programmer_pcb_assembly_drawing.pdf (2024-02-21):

J_OLMX1; CONN_JW1

View from Bottom side (Scale 4:1)

View from Top side (Scale 4:1)

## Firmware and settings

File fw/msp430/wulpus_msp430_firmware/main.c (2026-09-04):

/*
 * Copyright (C) 2024 ETH Zurich. All rights reserved.
 *
 * Author: Sergei Vostrikov, ETH Zurich
 *
 * Licensed under the Apache License, Version 2.0 (the "License");
 * you may not use this file except in compliance with the License.
 * You may obtain a copy of the License at
 *
 *      http://www.apache.org/licenses/LICENSE-2.0
 *
 * Unless required by applicable law or agreed to in writing, software
 * distributed under the License is distributed on an "AS IS" BASIS,
 * WITHOUT WARRANTIES OR CONDITIONS OF ANY KIND, either express or implied.
 * See the License for the specific language governing permissions and
 * limitations under the License.
 * 
 * SPDX-License-Identifier: Apache-2.0
 */

#include <msp430.h> 
#include "wulpus_sys.h"

#include "uslib_timers_isrs.h"

//// LOCAL MACRO DEFINITIONS AND VARIABLES ////

// First two Bytes of the measurement header
// Used to indicate the start of an US frame
#define MEAS_START_OF_FRAME_MASK 0xFF
// US measurement header
static uint8_t meas_header[4] = {0};
static uint16_t meas_frame_nr = 0;

// Empty config with MSP settings for US acquisition
msp_config_t msp_config;

// TX RX active config ID
uint8_t tx_rx_id = 0;

// A routine to get configuration package from nRF
static void getConfigPack(void);

// High level functions used in main
static void configAfterPowerUp(void);
static void receiveUssConfPackage(void);
static void usAcquisitionLoop(void);
static void prepareUSSAcquisition();

// Callbacks implementation
static void hsPllUnlockCallback(void);
static void saphSeqAcqDoneCallback(void);
static void slowTimerCc2Callback(void);
static void fastTimerCc0Callback(void);


int main(void)
{

    // Disable the GPIO power-on default high-impedance mode to activate
    // previously configured port settings
    PMM_unlockLPM5();

    // Initial configuration
    // Sets default parameters
    configAfterPowerUp();

    while(1)
    {
        // Set default parameters
        tx_rx_id = 0;
        meas_frame_nr = 0;

        // Power down HV PCB to save energy
        disableHvPcbDcDc();
        disableOpAmpSupply();
        disableHvPcbSupply();

        // Wait until we receive Uss configuration package from nRF
        receiveUssConfPackage();

        prepareUSSAcquisition();
        // Do measurements
        usAcquisitionLoop();
        }
    
    // Not reachable
	return 0;
}

void configAfterPowerUp(void)
{

    // Initialize DMA for SPI transfers and SPI for
    // nRF <-> MSP and MSP <-> HV MUX communication
    usDmaInit();
    usSpiInit();
    hvMuxInit();

    // Init BLE ready input and LED GPIOs
    initOtherGpios();
    // Init power switches
    initAllPowerSwitches();

    // Get default Ultrasound config
    getDefaultUsConfig(&msp_config);

    // Update the internal config of the ultrasound library
    setNewUsConfig(&msp_config);

    // Init timers
    timerSlowInit();
    timerFastInit();

    // Hook timers-related callback

    // Timer Slow CC2 callback enables HV DC-DC and opAmp
    TIMER_SLOW_CCR2_CALLBACK = &slowTimerCc2Callback;
    // Timer Slow CC0 callback reloads parameters of the capture
    // such as measurement period and dc-dc turn on time
    TIMER_SLOW_CCR0_CALLBACK = &reloadTimerSlowSwEvents;

    // Timer Fast CC1 callback triggers acquisition and
    // enables CC0 interrupt
    TIMER_FAST_CCR1_CALLBACK = &triggerAcqTimerFastEvent;
    // Timer Fast CC0 callback switches HV MUX to receive,
    // stops the DC-DC converter and the Fast timer
    TIMER_FAST_CCR0_CALLBACK = &fastTimerCc0Callback;

    // Hook other callbacks
    HS_PLL_UNLOCK_CALLBACK = &hsPllUnlockCallback;
    SAPH_SEQ_ACQ_DONE_CALLBACK = &saphSeqAcqDoneCallback;

    // Configure Ultrasound peripherals
    confUsSubsystem();

    // Configure the events of slow and fast timers
    confTimerSlowSwEvents();
    confTimerFastSwEvents();

    return;
}

static void receiveUssConfPackage(void)
{
    while(1)
    {
        // Sleep for 10 ms
        timerSlowDelay(327, LPM3_bits);

        // Check that nRF52 BLE connection is ready
        if (isBleReady())
        {
            // Receive configuration package from nRF
            getConfigPack();

            // Process received package and update Uss config
            if (extractUsConfig(usSpiGetRxPtr(), &msp_config))
            {
                // Update Ultrasound config
                setNewUsConfig(&msp_config);
                return;
            }
        }
    }
}

static void prepareUSSAcquisition(){
    enableHvPcbDcDc();

    // Configure Uss according to the new package
    confUsSubsystem();

    // Configure the events of slow and fast timers
    confTimerSlowSwEvents();
    confTimerFastSwEvents();

    // Power up HV PCB
    enableHvPcbSupply();
    // Enable Power for OPA836
    enableOpAmpSupply();
}

static void usAcquisitionLoop(void)
{

    bool no_error = true;

    while(1)
    {
        // Check if nRF52 BLE connection is ready
        if(isBleReady())
        {

            // Update the measurement header
            meas_header[0] = MEAS_START_OF_FRAME_MASK;
            meas_header[1] = tx_rx_id;
            meas_header[2] = (uint8_t) (meas_frame_nr & 0xFF);
            meas_header[3] = (uint8_t) (meas_frame_nr >> 8);
            memcpy((uint16_t *) 0x4000, &meas_header, 4);

            // Configure TX config (applied immediately)
            hvMuxConfTx(msp_config.txConfigs[tx_rx_id]);
            // Configure RX config (loaded into shift register but not latched)
            // Latching will occur in the timer interrupt after completion
            // of pulse generation
            hvMuxConfRx(msp_config.rxConfigs[tx_rx_id]);

            // Trigger ultrasound acquisition
            no_error = triggerUsAcq();
            if (no_error == false)
            {
                // Wait for timer to elapse
                waitTimerSlowElapse();
                continue;
            }

            // If instead aquisition sequencer finished as expected
            // and we reached this line, then
            // wait for the SPI DMA transaction to be completed

            // Wait for SPI DMA transmission to complete
            usWaitForSpiDmaRx();


            // Check the SPI RX buffer for restart command
            if (isRestartCondition(usSpiGetRxPtr()))
            {
                pauseTimerSlowSwEvents();
                return;
            }

            // Wait for timer to elapse
            waitTimerSlowElapse();

            // Increment measurement frame number
            // And TX RX configuration ID
            meas_frame_nr++;
            tx_rx_id++;
            if(tx_rx_id == msp_config.txRxConfLen)
                tx_rx_id = 0;
        }
    }
}

//// HELPER FUNCTIONS  ////

// Get configuration package from nRF
static void getConfigPack(void)
{
    // Initiate an SPI transaction to receive a config file
    // Clear TX buffer
    memset((uint16_t *) 0x4000, 0, (uint32_t)BYTES_PR_XFER_TX);
    // Start SPI transaction
    usStartSPI();

    // Enable DMA SPI interrupt
    // It will wake up the CPU from LPM0
    usSpiEnableDmaRxIsr();

    // Wait for SPI DMA RX to be completed
    usWaitForSpiDmaRx();
}

//// Callbacks implementation ////
static void hsPllUnlockCallback(void)
{
    // TI recommends to turn off USS module and check USSXT oscillator

    pllUnlockCallback();
}

static void saphSeqAcqDoneCallback(void)
{

    // Power Down the UUPS after the acquisition is complete
    UUPSCTL |= USSPWRDN;

    // Disable HV PCB DC-DC converters
    // and OpAmp

    // Disable HV and +5 V
    // disableHvPcbDcDc();
    // Disable RX OPA836
    // disableOpAmp();

    // if PLL unlock event occurs earlier the acquisition might be not valid
    if (isEventFlagSet(HS_PLL_UNLOCK_EVENT) == false)
    {
        // Enable DMA SPI interrupt
        // It will wake up the CPU from LPM0
        usSpiEnableDmaRxIsr();
        // Start SPI transaction
        usStartSPI();
    }
}

static void slowTimerCc2Callback(void)
{
    // Turn On DC-DCs
    enableHvPcbDcDc();
    // Enable RX OPA836
    enableOpAmp();
}

static void fastTimerCc0Callback(void)
{
    // Switch HV Mux
    hvMuxLatchOutput();
    // Disable HV DC-DC (we don't need V at this point)
    // disableHvDcDc();
    // Disable Fast Timer
    timerFastStop();
}

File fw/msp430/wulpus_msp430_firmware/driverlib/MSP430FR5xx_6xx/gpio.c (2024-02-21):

//*****************************************************************************
//
// gpio.c - Driver for the gpio Module.
//
//*****************************************************************************

//*****************************************************************************
//
//! \addtogroup gpio_api gpio
//! @{
//
//*****************************************************************************

#include "inc/hw_memmap.h"

#if defined(__MSP430_HAS_PORT1_R__) || defined(__MSP430_HAS_PORT2_R__) ||\
    defined(__MSP430_HAS_PORTA_R__)
#include "gpio.h"

#include <assert.h>

static const uint16_t GPIO_PORT_TO_BASE[] = {
    0x00,
#if defined(__MSP430_HAS_PORT1_R__)
    __MSP430_BASEADDRESS_PORT1_R__,
#elif defined(__MSP430_HAS_PORT1__)
    __MSP430_BASEADDRESS_PORT1__,
#else
    0xFFFF,
#endif
#if defined(__MSP430_HAS_PORT2_R__)
    __MSP430_BASEADDRESS_PORT2_R__,
#elif defined(__MSP430_HAS_PORT2__)
    __MSP430_BASEADDRESS_PORT2__,
#else
    0xFFFF,
#endif
#if defined(__MSP430_HAS_PORT3_R__)
    __MSP430_BASEADDRESS_PORT3_R__,
#elif defined(__MSP430_HAS_PORT3__)
    __MSP430_BASEADDRESS_PORT3__,
#else
    0xFFFF,
#endif
#if defined(__MSP430_HAS_PORT4_R__)
    __MSP430_BASEADDRESS_PORT4_R__,
#elif defined(__MSP430_HAS_PORT4__)
    __MSP430_BASEADDRESS_PORT4__,
#else
    0xFFFF,
#endif
#if defined(__MSP430_HAS_PORT5_R__)
    __MSP430_BASEADDRESS_PORT5_R__,
#elif defined(__MSP430_HAS_PORT5__)
    __MSP430_BASEADDRESS_PORT5__,
#else
    0xFFFF,
#endif
#if defined(__MSP430_HAS_PORT6_R__)
    __MSP430_BASEADDRESS_PORT6_R__,
#elif defined(__MSP430_HAS_PORT6__)
    __MSP430_BASEADDRESS_PORT6__,
#else
    0xFFFF,
#endif
#if defined(__MSP430_HAS_PORT7_R__)
    __MSP430_BASEADDRESS_PORT7_R__,
#elif defined(__MSP430_HAS_PORT7__)
    __MSP430_BASEADDRESS_PORT7__,
#else
    0xFFFF,
#endif
#if defined(__MSP430_HAS_PORT8_R__)
    __MSP430_BASEADDRESS_PORT8_R__,
#elif defined(__MSP430_HAS_PORT8__)
    __MSP430_BASEADDRESS_PORT8__,
#else
    0xFFFF,
#endif
#if defined(__MSP430_HAS_PORT9_R__)
    __MSP430_BASEADDRESS_PORT9_R__,
#elif defined(__MSP430_HAS_PORT9__)
    __MSP430_BASEADDRESS_PORT9__,
#else
    0xFFFF,
#endif
#if defined(__MSP430_HAS_PORT10_R__)
    __MSP430_BASEADDRESS_PORT10_R__,
#elif defined(__MSP430_HAS_PORT10__)
    __MSP430_BASEADDRESS_PORT10__,
#else
    0xFFFF,
#endif
#if defined(__MSP430_HAS_PORT11_R__)
    __MSP430_BASEADDRESS_PORT11_R__,
#elif defined(__MSP430_HAS_PORT11__)
    __MSP430_BASEADDRESS_PORT11__,
#else
    0xFFFF,
#endif
    0xFFFF,
#if defined(__MSP430_HAS_PORTJ_R__)
    __MSP430_BASEADDRESS_PORTJ_R__
#elif defined(__MSP430_HAS_PORTJ__)
    __MSP430_BASEADDRESS_PORTJ__
#else
    0xFFFF
#endif
};

void GPIO_setAsOutputPin(uint8_t selectedPort, uint16_t selectedPins) {

    uint16_t baseAddress = GPIO_PORT_TO_BASE[selectedPort];

    #ifndef NDEBUG
    if(baseAddress == 0xFFFF) {
        return;
    }
    #endif

    // Shift by 8 if port is even (upper 8-bits)
    if((selectedPort & 1) ^ 1) {
        selectedPins <<= 8;
    }

    HWREG16(baseAddress + OFS_PASEL0) &= ~selectedPins;
    HWREG16(baseAddress + OFS_PASEL1) &= ~selectedPins;
    HWREG16(baseAddress + OFS_PADIR) |= selectedPins;

    return;
}

void GPIO_setAsInputPin(uint8_t selectedPort, uint16_t selectedPins) {

    uint16_t baseAddress = GPIO_PORT_TO_BASE[selectedPort];

    #ifndef NDEBUG
    if(baseAddress == 0xFFFF) {
        return;
    }
    #endif

    // Shift by 8 if port is even (upper 8-bits)
    if((selectedPort & 1) ^ 1) {
        selectedPins <<= 8;
    }

    HWREG16(baseAddress + OFS_PASEL0) &= ~selectedPins;
    HWREG16(baseAddress + OFS_PASEL1) &= ~selectedPins;
    HWREG16(baseAddress + OFS_PADIR) &= ~selectedPins;
    HWREG16(baseAddress + OFS_PAREN) &= ~selectedPins;
}

void GPIO_setAsPeripheralModuleFunctionOutputPin(uint8_t selectedPort,
                                                      uint16_t selectedPins
                                                     ,uint8_t mode) {

    uint16_t baseAddress = GPIO_PORT_TO_BASE[selectedPort];

    #ifndef NDEBUG
    if(baseAddress == 0xFFFF) {
        return;
    }
    #endif

    // Shift by 8 if port is even (upper 8-bits)
    if((selectedPort & 1) ^ 1) {
        selectedPins <<= 8;
    }

    HWREG16(baseAddress + OFS_PADIR) |= selectedPins;
    switch (mode){
        case GPIO_PRIMARY_MODULE_FUNCTION:
            HWREG16(baseAddress + OFS_PASEL0) |= selectedPins;
            HWREG16(baseAddress + OFS_PASEL1) &= ~selectedPins;
            break;
        case GPIO_SECONDARY_MODULE_FUNCTION:
            HWREG16(baseAddress + OFS_PASEL0) &= ~selectedPins;
            HWREG16(baseAddress + OFS_PASEL1) |= selectedPins;
            break;
        case GPIO_TERNARY_MODULE_FUNCTION:
            HWREG16(baseAddress + OFS_PASEL0) |= selectedPins;
            HWREG16(baseAddress + OFS_PASEL1) |= selectedPins;
            break;
    }
}
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

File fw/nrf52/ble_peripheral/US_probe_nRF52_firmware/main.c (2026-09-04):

/*
 * Copyright (C) 2023 ETH Zurich. All rights reserved.
 *
 * Authors: Sebastian Frey, ETH Zurich
 *          Sergei Vostrikov, ETH Zurich
 *
 * Licensed under the Apache License, Version 2.0 (the "License");
 * you may not use this file except in compliance with the License.
 * You may obtain a copy of the License at
 *
 *      http://www.apache.org/licenses/LICENSE-2.0
 *
 * Unless required by applicable law or agreed to in writing, software
 * distributed under the License is distributed on an "AS IS" BASIS,
 * WITHOUT WARRANTIES OR CONDITIONS OF ANY KIND, either express or implied.
 * See the License for the specific language governing permissions and
 * limitations under the License.
 * 
 * SPDX-License-Identifier: Apache-2.0
 */


/** @file main.c
 *
 * @brief    nRF52 Acquisition PCB firmware main file
 *
 * This file contains the source code for the main file of the firmware
 * that runs on the nRF52 MCU on the Acquisition PCB. The purpose of this 
 * firmware is to receive US frames from the MSP430 through SPI and to 
 * send that data further to the receiver dongle through a BLE connection.
 * 
 */


#include "nrf_drv_gpiote.h"
#include "ble_advertising.h"
#include "ble_conn_params.h"
#include "nrf_sdh.h"
#include "nrf_ble_gatt.h"
#include "nrf_ble_qwr.h"
#include "app_timer.h"
#include "ble_nus.h"
#include "bsp_btn_ble.h"
#include "nrf_pwr_mgmt.h"

#include "nrf_drv_timer.h"
#include "nrf_drv_ppi.h"
#include "nrf_drv_spi.h"
#include "nrf_delay.h"

#include "us_spi.h"
#include "us_ble.h"
#include "us_defines.h"

#include "iis2dh.h"

// Buffers to store US data
ArrayList_type m_rx_buf[NUMBER_OF_XFERS*MAX_BUFFER_NUMBER_OF_US_FRAMES] = {0};

// Buffer to store commands from python
ArrayList_type m_tx_buf_1[NUMBER_OF_XFERS] = {0};

// Timer and counter to control SPI transactions
extern nrf_drv_timer_t timer_timer;
extern nrf_drv_timer_t timer_counter;
extern int buffer_counter;

// To check if SPI data can be relayed to BLE dongle
volatile bool ble_connected = false;

// A flag to signal that MSP config is received
volatile bool msp_conf_received = false;

volatile bool do_act_reading=false;


// Handle accelerometer as requested by GUI/User (see us_ble.c)
volatile bool accel_stream_enabled = false;
volatile bool accel_stream_requested = false;
volatile bool accel_stream_update_pending = false;

/**@brief Function for initializing the timer module.
 */
static void timers_init(void)
{
    ret_code_t err_code = app_timer_init();
    APP_ERROR_CHECK(err_code);
}


/**@brief Function for putting the chip into sleep mode.
 *
 * @note This function will not return.
 */
void sleep_mode_enter(void)
{
    uint32_t err_code = bsp_indication_set(BSP_INDICATE_IDLE);
    APP_ERROR_CHECK(err_code);

    // Prepare wakeup buttons.
    err_code = bsp_btn_ble_sleep_mode_prepare();
    APP_ERROR_CHECK(err_code);

    // Go to system-off mode (this function will not return; wakeup will cause a reset).
    err_code = sd_power_system_off();
    APP_ERROR_CHECK(err_code);
}



/**@brief Function for initializing power management.
 */
static void power_management_init(void)
{
    ret_code_t err_code;
    err_code = nrf_pwr_mgmt_init();
    APP_ERROR_CHECK(err_code);
}


/**@brief Function for handling the idle state (main loop).
 *
 * @details If there is no pending log operation, then sleep until next the next event occurs.
 */
static void idle_state_handle(void)
{
    nrf_pwr_mgmt_run();
}


/**
 * @brief Interrupt handler for data ready pin. The data ready signal comes
 * the MSP430 and signals a the availability of a new US frame. The SPI transaction to 
 * receive this US frame is started from here.
 */
void in_pin_handler(nrf_drv_gpiote_pin_t pin, nrf_gpiote_polarity_t action)
{
    // Check if the interrupt is from the data ready pin. If yes, start the SPI transactions
    if (pin == PIN_DATA_READY)
    {
        NRF_SPIM0->RXD.PTR = (uint32_t)&m_rx_buf[buffer_counter*NUMBER_OF_XFERS].buffer[0];

        /* Start every frame from a known state.
         *
         * nrf_drv_timer_enable() only issues TASKS_START, and the matching
         * nrf_drv_timer_disable() issues the deprecated TASKS_SHUTDOWN whose effect
         * on the COUNTER register is not clearly specified. Clearing both timers
         * here removes that dependency: the transfer counter is guaranteed to start
         * this frame at zero, so the burst can never end early, and timer_timer
         * always waits a full period before the first SPI START. */
        nrf_drv_timer_clear(&timer_counter);
        nrf_drv_timer_clear(&timer_timer);

        // Enable timer and counter to start the four SPI transactions
        nrf_drv_timer_enable(&timer_timer);
        nrf_drv_timer_enable(&timer_counter);
        do_act_reading =true;
    }
}

/**
 * @brief Function for configuring: PIN_IN pin for input, PIN_OUT pin for output,
 * and configures GPIOTE to give an interrupt on pin change.
 */
static void gpio_init(void)
{
    ret_code_t err_code;

    err_code = nrf_drv_gpiote_init();
    APP_ERROR_CHECK(err_code);

    // Configure NRF52 LED on Acquisition PCB
    nrf_drv_gpiote_out_config_t out_config = GPIOTE_CONFIG_OUT_SIMPLE(false);
    err_code = nrf_drv_gpiote_out_init(LED_NRF52, &out_config);
    APP_ERROR_CHECK(err_code);

    // BLE connection ready GPIO out
    nrf_drv_gpiote_out_config_t out_config_ble_ready = GPIOTE_CONFIG_OUT_SIMPLE(false);
    err_code = nrf_drv_gpiote_out_init(PIN_BLE_CONN_READY, &out_config_ble_ready);
    APP_ERROR_CHECK(err_code);

    // SPI data ready GPIO in
    nrf_drv_gpiote_in_config_t in_config_data_ready = GPIOTE_CONFIG_IN_SENSE_LOTOHI(true);
    in_config_data_ready.pull = NRF_GPIO_PIN_NOPULL;
    err_code = nrf_drv_gpiote_in_init(PIN_DATA_READY, &in_config_data_ready, in_pin_handler);
    APP_ERROR_CHECK(err_code);
    
    // Enable interrupt for data ready
    nrf_drv_gpiote_in_event_enable(PIN_DATA_READY, true);

}


static void apply_accel_mode_if_pending(void)
{
    if (!accel_stream_update_pending)
        return;

    accel_stream_enabled = accel_stream_requested;
    IIS2DH_set_streaming_enabled(accel_stream_enabled);
    accel_stream_update_pending = false;
}
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

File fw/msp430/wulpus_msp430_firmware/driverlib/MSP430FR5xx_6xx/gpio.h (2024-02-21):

//*****************************************************************************
//
// gpio.h - Driver for the GPIO Module.
//
//*****************************************************************************

#ifndef __MSP430WARE_GPIO_H__
#define __MSP430WARE_GPIO_H__

#include "inc/hw_memmap.h"

#if defined(__MSP430_HAS_PORT1_R__) || defined(__MSP430_HAS_PORT2_R__) ||\
    defined(__MSP430_HAS_PORTA_R__)

//*****************************************************************************
//
// If building with a C++ compiler, make all of the definitions in this header
// have a C binding.
//
//*****************************************************************************
#ifdef __cplusplus
extern "C"
{
#endif

//*****************************************************************************
//
// The following are values that can be passed to the selectedPort parameter
// for functions: GPIO_setAsOutputPin(), GPIO_setAsInputPin(),
// GPIO_setAsPeripheralModuleFunctionOutputPin(),
// GPIO_setAsPeripheralModuleFunctionInputPin(), GPIO_setOutputHighOnPin(),
// GPIO_setOutputLowOnPin(), GPIO_toggleOutputOnPin(),
// GPIO_setAsInputPinWithPullDownResistor(),
// GPIO_setAsInputPinWithPullUpResistor(), GPIO_getInputPinValue(),
// GPIO_selectInterruptEdge(), GPIO_enableInterrupt(), GPIO_disableInterrupt(),
// GPIO_getInterruptStatus(), and GPIO_clearInterrupt().
//
//*****************************************************************************
#define GPIO_PORT_P1                                                          1
#define GPIO_PORT_P2                                                          2
#define GPIO_PORT_P3                                                          3
#define GPIO_PORT_P4                                                          4
#define GPIO_PORT_P5                                                          5
#define GPIO_PORT_P6                                                          6
#define GPIO_PORT_P7                                                          7
#define GPIO_PORT_P8                                                          8
#define GPIO_PORT_P9                                                          9
#define GPIO_PORT_P10                                                        10
#define GPIO_PORT_P11                                                        11
#define GPIO_PORT_PA                                                          1
#define GPIO_PORT_PB                                                          3
#define GPIO_PORT_PC                                                          5
#define GPIO_PORT_PD                                                          7
#define GPIO_PORT_PE                                                          9
#define GPIO_PORT_PF                                                         11
#define GPIO_PORT_PJ                                                         13
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

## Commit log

2023-10-20 Cleaned the project, measured the power consumption of the firmware with implemented buffering, added Changelog
2023-11-09 First draft of the optimized MUX switching algorithm + integration in the GUI
2023-11-28 Update design files Acquisition PCB
    Add Board-to-wire connector J5, giving access to VCC, GND and two GPIO's of each MCU
    Add one button for each MCU (not mounted by default)
    Marked various components as "Do not mount" (R33, R21, R32, R2, R3, C5, C46)
    Replaced battery connector (new DF52-2S-0.8H(21)
    Replaced R35 with 0 Ohm jumper
    [00_POWER.SchDoc, 01_NRF52.SchDoc, 02_MSP430.SchDoc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]
2023-11-28 Create output job file to generate documentation
    Generated production files (Assembly drawing, BOM, Gerber files, Drill files, Pick&Place files)
    [PCB1.GBL, PCB1.GBO, PCB1.GBP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]
2023-11-28 Prepare Acquisition PCB for pull request
    Add changelog
2023-11-28 Change design files of HV PCB
    - Marked various components as "Do not mount" (C9, C10, C11, C20, R9, C16)
    - Replaced high voltage multiplexer HV2708 to HV2707
    - Replaced MOSFET MCP1402 to MCP1416
    - Replaced R13, R14, R19 with 0 Ohm jumper
    - Replaced R15 with 10 nF CAP
    - Replaced C17 with 100 Ohm resistor
    [00_POWER.SchDoc, 01_TRANSDUCERS.SchDoc, PCB1.PcbDoc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]
2023-11-28 Created output job file for docmentation and production
    - Generated production files (Assembly drawing, BOM, Gerber files, Drill files, Pick&Place files)
    [PCB1.GBL, PCB1.GBO, PCB1.GBP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]
2023-11-28 Prepare HV PCB for pull request
    Added chengelog
2023-12-08 Added BOM list as Excel
    [wulpus_acq_pcb.PrjPcb, wulpus_acq_pcb_bom.xlsx, wulpus_hv_mux_bom.xlsx]
2024-01-06 Loading raw data examples
    Also changed labels/buttons in GUIs.
2024-01-09 Fixed switching optimization bug + cleaned example notebook
2024-01-09 Fixed a bug with not loading optimized switching parameter from the file. Added sample data. Cleaned jupyter example notebook.
2024-02-02 Update fabrication files
    - update fabrication filey of acquisition PCB, with correct stackup and adjusted trace widths
    - add msp430 programmer pcb
    - add nrf52 programmer pcb
    [01_NRF52.SchDoc, 02_MSP430.SchDoc, 03_MSP430_AFE.SchDoc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]
2024-03-11 Updated assembly drawing
    Improved assembly drawing for external assembly
    [00_POWER.SchDoc, PcbLib1.PcbLib, Schlib1.SchLib]
2024-12-16 Issue 17 addressed
    - Replaced R1, R5, R6, R8, R9, R10, R11, R13 with 0.1Ohm, 250mW resistors
    - Placed a weak pull-down resistor to fix the disabled state of TLV62569 by default
    [00_POWER.SchDoc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]
2024-12-20 Added silicone package design files, updated Readmes and changelogs
    [wulpus_inside_mold_fdm.stl, wulpus_inside_mold_resin.stl, wulpus_outside_mold_fdm.stl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]
2025-01-17 Adjusted RF circuit and layout
    - Removed mounting hole M3
    - Moved traces for button and led away
    - Clean up of the routing to have space for matching circuit on the bottom layer
    - Kept a clean solid GND on the layer directly below
    - Add shielding vias along the RF trace
    [00_POWER.SchDoc, 01_NRF52.SchDoc, 02_MSP430.SchDoc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]
2025-02-10 Update stackup
    updated stackup and 50ohm RF trace
    regenerated fabrication files
    [PCB1.GBL, PCB1.GBO, PCB1.GBP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]
2025-02-10 updated changelog for acquisition PCB
2025-02-10 update changelog for acquisition PCB
2025-02-11 minor changes RF circuit
    - set version number to 1.2.1
    - move RF CAP slightly closer to nRF
    - impedance at nRF RF pin 61ohm
    [PCB1.GBL, PCB1.GBO, PCB1.GBP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]
2025-02-12 Updated HV PCB stackup
    - Updated stackup
    - Regenerated fabrication files and stackup information
    [PCB1.GBL, PCB1.GBO, PCB1.GBP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]
2025-03-23 Improved U8 footprint to improve PCBA yield, completed task #33
    [PCB1.GBL, PCB1.GBO, PCB1.GBP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]
2025-04-02 Expanded interpin distance for U8 to 0.22 mm plus updated siklscreen
    [PCB1.GBL, PCB1.GBO, PCB1.GBP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]
2025-09-18 Initially power down HV PCB to save energy
2025-09-25 Revert bug in firmware (checking runtime for new config doesn't seem to work)
    [main.c, wulpus_sys.c]
2025-11-12 Extend printing for debugging
2025-11-18 Fix error: scanning wasn't possible on devices without bluetooth chipset
2026-04-02 Add optional accelerometer streaming controlled by config packet
    This change keeps backward-compatible streaming behavior for ultrasound data while making accelerometer streaming optional.
    Tested the following cases:
    1. accelerometer requested
    - firmware starts correctly
    - ultrasound data streams correctly
    - accelerometer data is appended to outgoing frames
    2. accelerometer not requested
    - firmware starts correctly
    - ultrasound data streams correctly
    - accelerometer remains off
    3. repeated configuration updates
    - switching between enabled and disabled modes works correctly
    [iis2dh.h, main.c, us_ble.c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]
2026-08-04 update antenna and matching circuit
    [01_NRF52.SchDoc, PcbLib1.PcbLib, Schlib1.SchLib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]
2026-08-04 Adjust RF routing
    [PCB1.PcbDoc]
2026-08-04 update docs and fabrication files
    [PCB1.GBL, PCB1.GBO, PCB1.GBP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]
2026-08-31 prepare for release 1.2.4
    [03_MSP430_AFE.SchDoc, PCB1.PcbDoc, wulpus_acq_pcb_bom.xlsx]
